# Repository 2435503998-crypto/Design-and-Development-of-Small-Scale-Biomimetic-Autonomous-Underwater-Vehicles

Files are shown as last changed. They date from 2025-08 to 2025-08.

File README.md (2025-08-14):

# Biomimetic Robotic Fish

This project is a MSc project — ”Design and Development of Small-Scale Biomimetic   Autonomous Underwater Vehicles“ Aims to design a robot goldfish(~10 cm in length), controlled by an ESP32-C3 microcontroller.  
It implements closed-loop tail fin oscillation control based on angle sensor feedback and supports Bluetooth-based mode switching and data transmission.  
The outer shell and tail fin support structure are 3D-printed, resulting in a compact, modular, and easily maintainable design.

---

## Features
- **Closed-loop control**: PD control based on angle sensor feedback for precise tail oscillation.
- **Bluetooth communication**: Wireless mode switching (start, straight, turn, stop).
- **Modular design**: 3D-printed shell and tail support for easy assembly and replacement.
- **Visual debugging**: Serial output of reference angle, measured angle, and control signal for performance analysis.

---

## Repository Structure
```
RobotGoldfish/
│
├─ code/        # Control programs
├─ simulation/  # Simulink model and simulation results
├─ data/        # land_test.csv
├─ hardware/    # 3D models, BOM
└─ README.md    # Project description
```

## Hardware Requirements
- uPesy ESP32-C3 Mini board  
- Single-PWM-input motor driver  
- Angular position sensor  
- 3D-printed shell & tail support
- 3D-printed gears
- Li-ion battery & wireless charging module (optional)  

---

## Author
Haodi Zhang  
University of Glasgow  
2025

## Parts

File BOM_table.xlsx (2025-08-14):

No. | Name | Qty
1 | Shell 1 | 1 | Customized design
2 | Shell 2 | 1 | Customized design
3 | Tail | 1 | Customized design
4 | Motor Mount | 1 | Customized design
5 | Spur Gear | 1 | Module 0.5 / 20 teeth
6 | Custom Hybrid Gear |  | Custom design
7 | Caudal Fin |  | TPU sheet
8 | Shaft |  | Ø4mm
9 | DC Motor | 1 | 3V, 240 RPM, Ø6mm
10 | Anguar Sensor | 1 | 4.5.3 KSA07W Hall Angular Sensor
11 | Control Board (ESP32-C3) | 1 | ESP32-C3 Mini
12 | Motor Driver Module | 1 | PWM input, 3.7V compatible
13 | Li-Po Battery | 1 | 3.7V, 100 mAh
14 | Wireless Charging Module | 1 | 4.2V, Ø8 mm coil
15 | Waterproof Seal skin | 1 | IIR Material
16 | Screws | 2 | M2, 6 mm
17 | Wires | N/A | 28 AWG

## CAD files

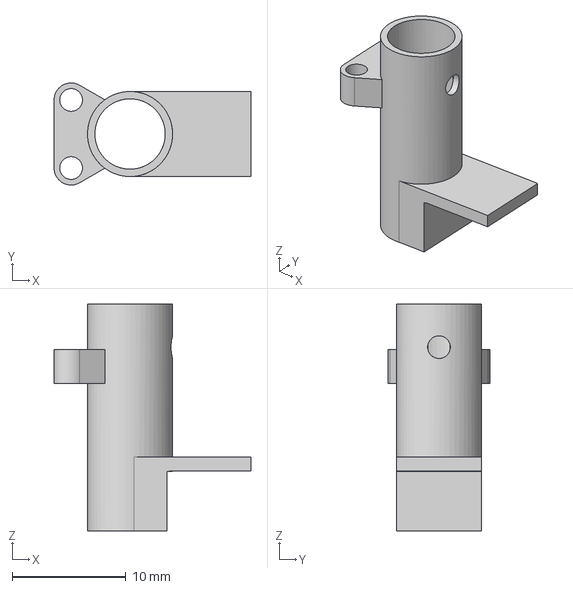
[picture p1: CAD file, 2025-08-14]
Mount.step
17.3 x 9.00 x 20.0 mm

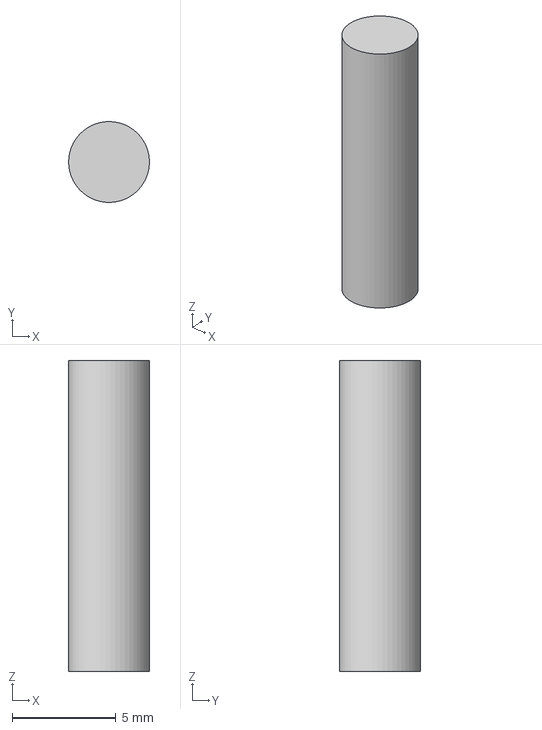
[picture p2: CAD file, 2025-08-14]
Shaft.step
3.90 x 3.90 x 15.0 mm

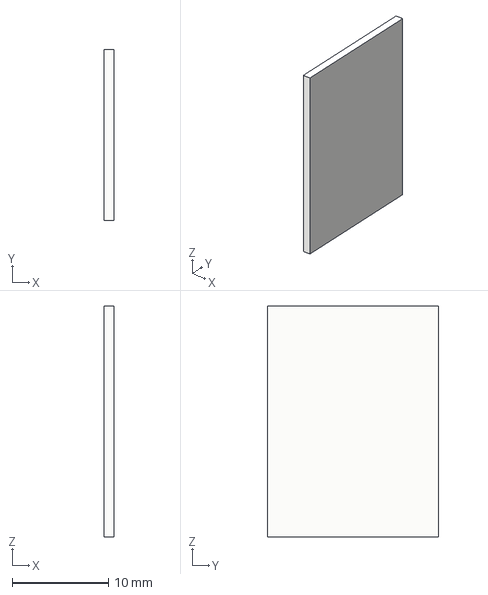
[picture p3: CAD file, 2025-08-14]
Controller.step
1.00 x 17.8 x 24.0 mm

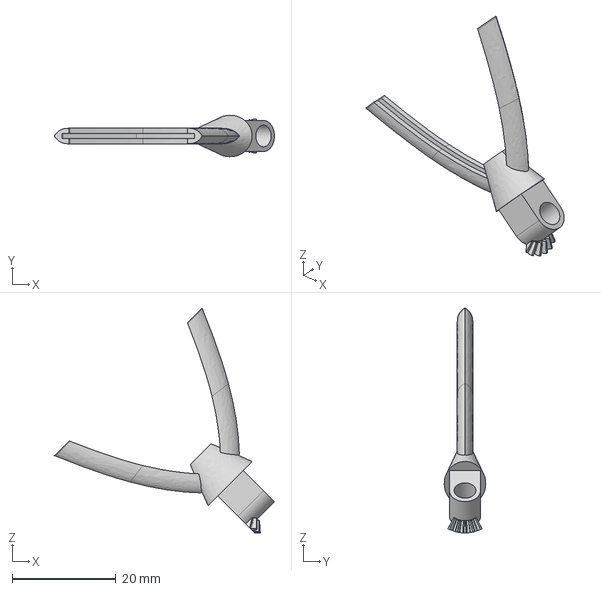
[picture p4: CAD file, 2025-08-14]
Tail_1.step
42.3 x 7.99 x 43.3 mm

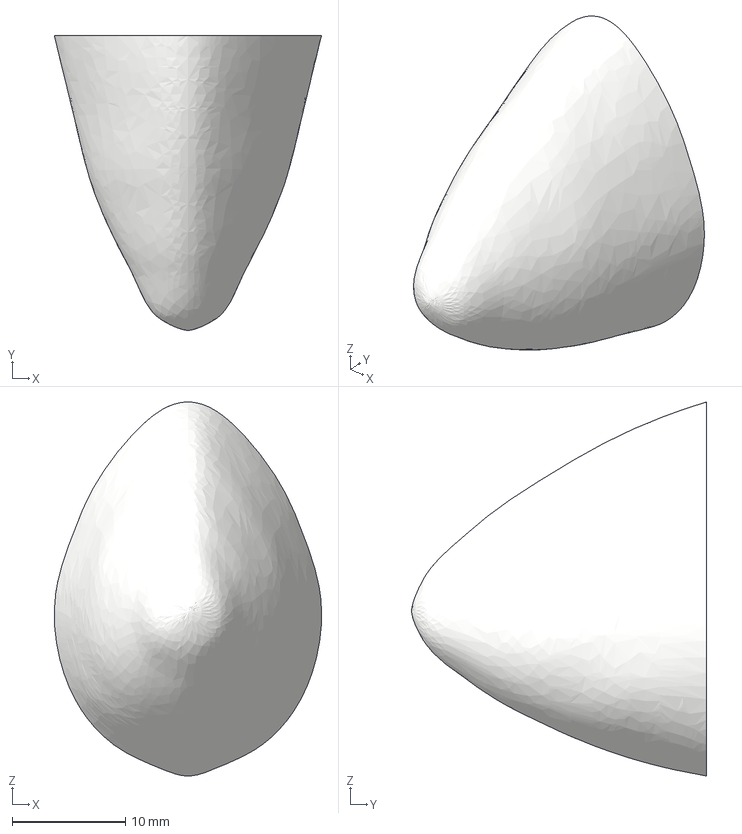
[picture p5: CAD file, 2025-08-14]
Shell_1.step
23.6 x 26.0 x 33.0 mm

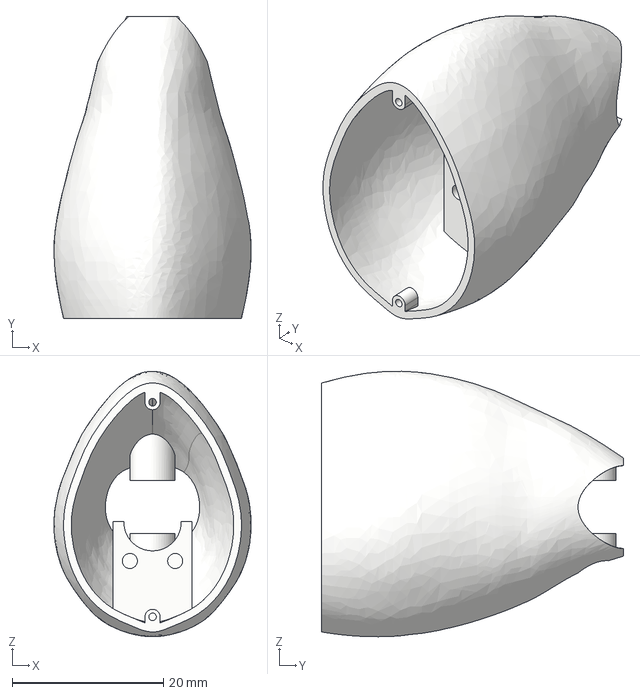
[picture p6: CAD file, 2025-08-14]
Shell _2.step
26.1 x 40.0 x 35.2 mm

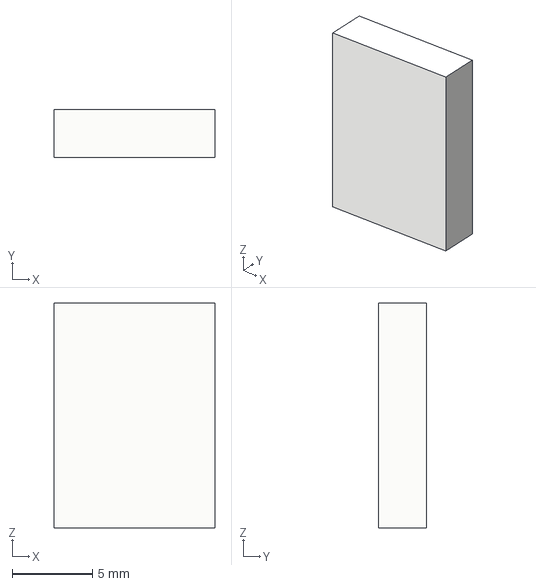
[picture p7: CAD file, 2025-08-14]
Driver.step
10.0 x 3.00 x 14.0 mm

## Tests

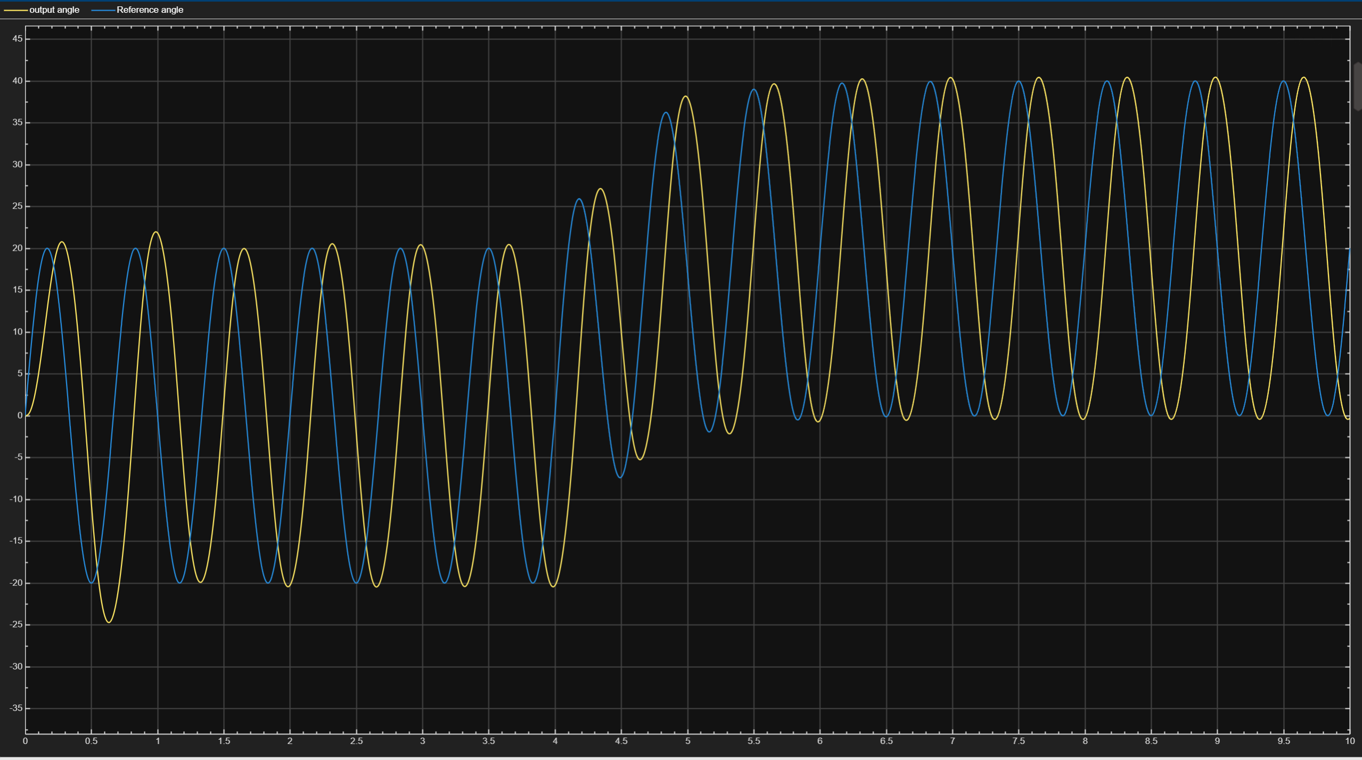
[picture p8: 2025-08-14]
Simulation_result.png

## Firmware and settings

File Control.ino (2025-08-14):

#include <Arduino.h>
#include <BLEDevice.h>
#include <BLEUtils.h>
#include <BLEServer.h>
#include <math.h>
#include <string.h>

/*********** ====== Hardware & Channels ====== ***********/
static const int ESC_Pin     = 7;     // PWM output pin
static const int ESC_Channel = 0;     // LEDC channel
static const int PWM_freq    = 50;    // 50 Hz (20 ms period)
static const int PWM_bits    = 10;    // 10-bit (0..1023)

static const int anglePin = 0;        // ADC pin (ESP32-C3 ADC0)
static const int ADC_MAX  = 4095;     // 12-bit ADC

/*********** ====== Reference Signal ====== ***********/
static const float A_deg   = 20.0f;   // amplitude (deg)
static const float f_ref   = 2.0f;    // reference frequency (Hz)

/*********** ====== Control Period ====== ***********/
static const float Ts = 0.02f;                 // 20 ms control period
static const unsigned long Ts_ms = (unsigned long)(Ts * 1000.0f);

/*********** ====== PD Controller (with filtered D) ====== ***********/
// PD form: u = Kp * e - Kd * theta_dot_filt
static const float Kp = 2.6f;                 // proportional gain (start from 0.8~1.5)
static const float Kd = 0.21f;                 // derivative gain (start small)
static const float fd_d = 8.0f;                // D-term low-pass cutoff (Hz)
static const float beta_d = 1.0f - expf(-2.0f * PI * fd_d * Ts);

/*********** ====== Measurement Low-pass Filter ====== ***********/
static const float fc_meas = 5.0f;             // position LPF cutoff (Hz)
static const float alpha   = 1.0f - expf(-2.0f * PI * fc_meas * Ts);

/*********** ====== PWM Map & Limits ====== ***********/
static const int PWM_CENTER_US  = 1500;
static const int PWM_RANGE_US   = 500;
static const int PWM_MIN_US     = 1000;
static const int PWM_MAX_US     = 2000;
static const int DEAD_BAND_US   = 20;

/*********** ====== Soft-start ====== ***********/
static const float ramp_time_s = 3.0f;

/*********** ====== Output Scale ====== ***********/
static const float OUTPUT_SCALE = 1.0f;

/*********** ====== Turn-cycle Params ====== ***********/
static const float TURN_OFFSET_DEG         = 15.0f;        // left-turn bias (deg)
static const unsigned long TURN_DELAY_MS   = 5000UL;       // go straight 5 s, then prepare turn
static const unsigned long TURN_HOLD_MS    = 2000UL;       // hold turn 2 s
static const float CENTER_TOL_DEG          = 2.0f;         // re-center threshold (±2°)

/*********** ====== Internal States ====== ***********/
static float angle_filt_rad = 0.0f;
static float last_angle_filt_rad = 0.0f;
static float theta_dot_filt = 0.0f;

static unsigned long t0_ms   = 0;
static unsigned long last_ms = 0;

static int mode = 0;                 // 0=idle (hold center), 1=run (with turn cycle)
static float turn_offset_deg = 0.0f;
static unsigned long cycle_anchor_ms = 0;
static unsigned long turn_start_ms   = 0;

enum TurnState { TURN_IDLE = 0, TURN_WAIT_CENTER, TURN_LEFT };
static TurnState turn_state = TURN_IDLE;

/*********** ====== BLE (UART-like) ====== ***********/
BLEServer* pServer = nullptr;
BLECharacteristic* pTxCharacteristic = nullptr;  // notify (device -> phone)
BLECharacteristic* pRxCharacteristic = nullptr;  // write  (phone  -> device)
bool deviceConnected = false;

// Nordic UART Service (NUS)-like UUIDs
#define SERVICE_UUID            "6E400001-B5A3-F393-E0A9-E50E24DCCA9E"
#define CHARACTERISTIC_UUID_TX  "6E400003-B5A3-F393-E0A9-E50E24DCCA9E" // notify
#define CHARACTERISTIC_UUID_RX  "6E400002-B5A3-F393-E0A9-E50E24DCCA9E" // write

/*********** ====== Helpers ====== ***********/
static inline float deg2rad(float d){ return d * PI / 180.0f; }
static inline float rad2deg(float r){ return r * 180.0f / PI; }

void writePWM_us(int pulse_us){
  pulse_us = constrain(pulse_us, PWM_MIN_US, PWM_MAX_US);
  int duty = (int)lround((pulse_us / 20000.0f) * ((1 << PWM_bits) - 1));
  ledcWrite(ESC_Channel, duty);
}

void ESC_Init(){
  ledcSetup(ESC_Channel, PWM_freq, PWM_bits);
  ledcAttachPin(ESC_Pin, ESC_Channel);
  writePWM_us(PWM_CENTER_US);
}

float read_angle_centered_rad(){
  int adc = analogRead(anglePin);
  float angle_abs_rad = (adc / (float)ADC_MAX) * 2.0f * PI; // [0..2π)
  float centered = angle_abs_rad - PI;                      // [-π..π)
  while (centered >  PI) centered -= 2.0f * PI;
  while (centered <= -PI) centered += 2.0f * PI;
  return centered;
}

static inline void reset_cycle_logic(unsigned long now_ms){
  turn_offset_deg = 0.0f;
  turn_state = TURN_IDLE;
  cycle_anchor_ms = now_ms;
  theta_dot_filt = 0.0f;
}

/*********** ====== BLE Callbacks ====== ***********/
class MyServerCallbacks: public BLEServerCallbacks {
  void onConnect(BLEServer* pServer) override { deviceConnected = true; }
  void onDisconnect(BLEServer* pServer) override { deviceConnected = false; }
};

class RxCallbacks: public BLECharacteristicCallbacks {
  void onWrite(BLECharacteristic* pChar) override {
    std::string rx = pChar->getValue();
    if (rx.empty()) return;

    char c = rx[0];
    unsigned long now = millis();
    if (c == '1'){
      mode = 1;
      reset_cycle_logic(now);
      Serial.println("BLE: Start loop");
    } else if (c == '2'){
      mode = 0;
      turn_offset_deg = 0.0f;
      turn_state = TURN_IDLE;
      writePWM_us(PWM_CENTER_US);
      Serial.println("BLE: Stop & hold center");
    }
  }
};

void BLE_Init(){
  BLEDevice::init("AUV-ESP32C3");
  pServer = BLEDevice::createServer();
  pServer->setCallbacks(new MyServerCallbacks());

  BLEService *pService = pServer->createService(SERVICE_UUID);

  // TX: notify (device -> phone)
  pTxCharacteristic = pService->createCharacteristic(
                        CHARACTERISTIC_UUID_TX,
                        BLECharacteristic::PROPERTY_NOTIFY);

  // RX: write (phone -> device)
  pRxCharacteristic = pService->createCharacteristic(
                        CHARACTERISTIC_UUID_RX,
                        BLECharacteristic::PROPERTY_WRITE |
                        BLECharacteristic::PROPERTY_WRITE_NR);
  pRxCharacteristic->setCallbacks(new RxCallbacks());

  pService->start();
  pServer->getAdvertising()->start();
}

/*********** ====== Arduino Main ====== ***********/
void setup(){
  Serial.begin(115200);
  ESC_Init();
  BLE_Init();

  angle_filt_rad = read_angle_centered_rad();
  last_angle_filt_rad = angle_filt_rad;
  t0_ms = last_ms = millis();
  cycle_anchor_ms = t0_ms;

  const char* header = "ref_deg,meas_deg,u_cmd\n";
  if (pTxCharacteristic){
    pTxCharacteristic->setValue((uint8_t*)header, strlen(header));
    pTxCharacteristic->notify();
  }
  Serial.print(header);

  Serial.println("Controls: Serial or BLE RX -> send '1' to RUN, '2' to IDLE(center).");
}

void loop(){
  unsigned long now = millis();

  /******** Serial one-key control: '1' run, '2' idle(center) ********/
  if (Serial.available()){
    char c = (char)Serial.read();
    if (c == '1'){
      mode = 1;
      reset_cycle_logic(now);
      Serial.println("Start loop");
    } else if (c == '2'){
      mode = 0;
      turn_offset_deg = 0.0f;
      turn_state = TURN_IDLE;
      writePWM_us(PWM_CENTER_US);
      Serial.println("Stop & hold center");
    }
  }

  // Fixed-rate loop
  if (now - last_ms < Ts_ms) return;
  last_ms += Ts_ms;

  float t = (now - t0_ms) / 1000.0f;

  /******** Reference signal ********/
  float theta_ref;
  if (mode == 1){
    // Turning state machine
    switch (turn_state){
      case TURN_IDLE:
        if ((now - cycle_anchor_ms) >= TURN_DELAY_MS){
          turn_state = TURN_WAIT_CENTER;
          turn_offset_deg = 0.0f;
        }
        break;
      case TURN_WAIT_CENTER:
        if (fabsf(rad2deg(angle_filt_rad)) <= CENTER_TOL_DEG){
          turn_state = TURN_LEFT;
          turn_offset_deg = TURN_OFFSET_DEG;  // left turn
          turn_start_ms = now;
        }
        break;
      case TURN_LEFT:
        if ((now - turn_start_ms) >= TURN_HOLD_MS){
          turn_offset_deg = 0.0f;
          turn_state = TURN_IDLE;
          cycle_anchor_ms = now;
        }
        break;
    }
    theta_ref = deg2rad(A_deg) * sinf(2.0f * PI * f_ref * t) + deg2rad(turn_offset_deg);
  } else {
    theta_ref = 0.0f;  // idle: hold center
  }

  /******** Measurement & LPF ********/
  float angle_meas = read_angle_centered_rad();
  angle_filt_rad += alpha * (angle_meas - angle_filt_rad);

  // Estimate angular velocity with LPF (for D-term)
  float theta_dot = (angle_filt_rad - last_angle_filt_rad) / Ts;
  theta_dot_filt += beta_d * (theta_dot - theta_dot_filt);
  last_angle_filt_rad = angle_filt_rad;

  /******** PD Control (idle -> no control) ********/
  float u_cmd = 0.0f;
  if (mode == 1){
    float e = theta_ref - angle_filt_rad;
    u_cmd = Kp * e - Kd * theta_dot_filt;

    // Soft-start and output limit in normalized [-1, 1]
    float ramp = (t < ramp_time_s) ? (t / ramp_time_s) : 1.0f;
    if (u_cmd >  ramp) u_cmd =  ramp;
    if (u_cmd < -ramp) u_cmd = -ramp;
    if (u_cmd >  1.0f) u_cmd =  1.0f;
    if (u_cmd < -1.0f) u_cmd = -1.0f;

    u_cmd *= OUTPUT_SCALE;
  } else {
    writePWM_us(PWM_CENTER_US);  // force center when idle
  }

  /******** PWM output (only in RUN mode) ********/
  if (mode == 1){
    int pwm_us = PWM_CENTER_US + (int)lround(u_cmd * PWM_RANGE_US);
    if (abs(pwm_us - PWM_CENTER_US) < DEAD_BAND_US) pwm_us = PWM_CENTER_US;  // dead-band
    writePWM_us(pwm_us);
  }

  /******** Telemetry (BLE + Serial) ********/
  float value1 = 180.0f + rad2deg(theta_ref);       // ref_deg, shifted for plotting
  float value2 = 180.0f + rad2deg(angle_filt_rad);  // meas_deg, shifted
  float value3 = u_cmd * 50.0f;                     // control signal scaled

  char buf[64];
  int n = snprintf(buf, sizeof(buf), "%.2f,%.2f,%.2f\n", value1, value2, value3);
  if (deviceConnected && pTxCharacteristic && n > 0) {
    pTxCharacteristic->setValue((uint8_t*)buf, n);
    pTxCharacteristic->notify();
  }
  Serial.write((uint8_t*)buf, n);
}
